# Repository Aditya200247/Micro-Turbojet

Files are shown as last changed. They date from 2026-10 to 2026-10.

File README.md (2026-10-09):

# Micro Turbojet: Parametric CAD + Cycle Physics

A parametric CAD model of a small **KJ66-class turbojet** (about 110 mm diameter, 234 mm long) built with [CadQuery](https://github.com/CadQuery/cadquery), plus a first-order thermodynamic estimate of how it would perform. Built as a college science/robotics project study, with the long-term goal of powering a small model fighter jet.

<table>
  <tr>
    <th align="center">Full-section view</th>
    <th align="center">Open-body (cutaway) view</th>
  </tr>
  <tr>
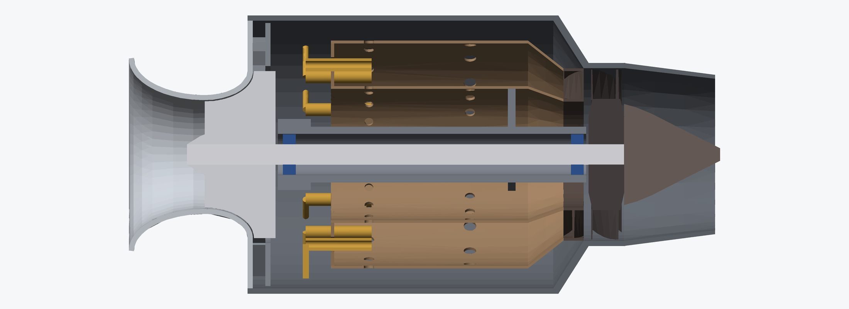
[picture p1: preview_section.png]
Full-section view of the turbojet
    <td align="center"></td>
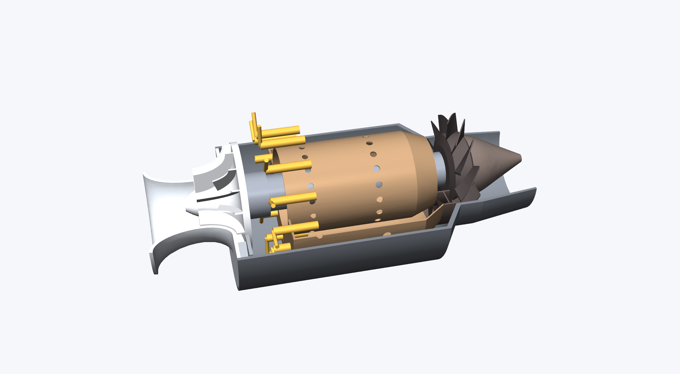
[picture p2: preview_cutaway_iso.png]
Open-body cutaway view of the turbojet
    <td align="center"></td>
  </tr>
  <tr>
    <th align="center" colspan="2">Open-body (cutaway) view, from above: compressor, combustor, turbine and nozzle</th>
  </tr>
  <tr>
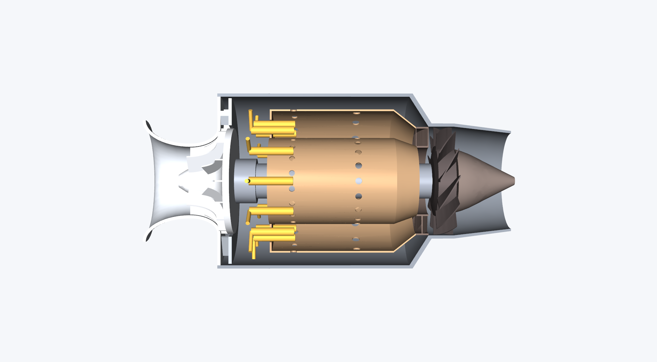
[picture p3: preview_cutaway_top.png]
Top-down cutaway of the turbojet
    <td align="center" colspan="2"></td>
  </tr>
</table>

> **Status: design study, not a validated engine.** The geometry is a believable first draft. It has not been CFD-checked, stress-checked, balanced, built or run. See [Known limitations](#known-limitations) before you machine anything.

---

## Contents

1. [Repository layout](#repository-layout)
2. [How a turbojet works](#how-a-turbojet-works)
3. [The physics, stage by stage](#the-physics-stage-by-stage)
4. [Results for this design](#results-for-this-design)
5. [CAD model description](#cad-model-description)
6. [Known limitations](#known-limitations)
7. [Rebuilding the model](#rebuilding-the-model)
8. [Scaling up to a 1–2 m fighter jet](#scaling-up-to-a-12-m-fighter-jet)
9. [Safety](#safety)
10. [References](#references)

---

## Repository layout

```
cad/        STEP (editable, named parts, colours) and STL (mesh) exports
            turbojet.step / .stl             complete engine
            turbojet_cutaway.step / .stl     top half of static shells removed
images/     preview renders
src/
  build_turbojet.py    parametric model, 16 named parts -> STEP/STL
  build_cutaway.py     open-body variant
  engine_calcs.py      mean-line cycle estimate used in this README
```

Units are **millimetres**. The engine axis is **+X**; the inlet lip is at x = 0 and the nozzle exit at x ≈ 234.

---

## How a turbojet works

A turbojet is a heat engine running the **Brayton cycle**, in four steps:

1. **Compress** the incoming air (compressor wheel and diffuser).
2. **Add heat** by burning fuel in it at roughly constant pressure (combustor).
3. **Expand** part of the hot gas through a turbine that extracts *just enough* work to drive the compressor.
4. **Expand the rest** through a nozzle into a fast jet. The leftover energy becomes thrust.

```mermaid
flowchart LR
    A["1 Inlet<br/>ambient air"] --> B["2 Compressor<br/>centrifugal, PR ≈ 3"]
    B --> C["3 Combustor<br/>annular, fuel added"]
    C --> D["4 Turbine<br/>axial, drives shaft"]
    D --> E["5 Nozzle<br/>jet = thrust"]
    D -. shaft work .-> B
```

Everything in the engine is one rotating assembly (compressor wheel, shaft, turbine wheel) spinning at **100,000+ RPM**, supported on two bearings.

---

## The physics, stage by stage

Notation: `T` temperature, `P` pressure, `U` blade speed, `c_p` specific heat, `γ` heat-capacity ratio, `η` efficiency, `ṁ` mass flow. Subscript `0` means total (stagnation) conditions.

### 1. Compressor: centrifugal wheel

Work input comes from **Euler's turbomachinery equation**. With no swirl at the inlet:

$$w_c = \sigma\,U_2^{2}$$

- `U₂ = πD₂N/60` is the blade tip speed (D₂ = 66 mm here).
- `σ` is the **slip factor**: the air leaves the wheel slightly "lagging" the blade. For radial blades the Wiesner correlation gives `σ = 1 − 1/Z^0.7`, where Z is the blade count (16 counting splitters, so σ ≈ 0.86).

The temperature rise and resulting **pressure ratio** follow from the isentropic relation with compressor efficiency η_c:

$$\Delta T_{0c}=\frac{w_c}{c_{p}},\qquad
PR_c=\left(1+\frac{\eta_c\,\Delta T_{0c}}{T_{01}}\right)^{\frac{\gamma}{\gamma-1}}$$

The pressure ratio rises as roughly **N²**, which is why these engines need such huge rotational speeds. The inducer's relative tip Mach number (`M = √(U₁ₜ² + Cₐ²)/a`) is kept below about 0.9 to avoid shock losses at the intake.

### 2. Diffuser

The air leaves the wheel at over 400 m/s, which is fast and kinetically "wasteful." The vaned diffuser slows it down, converting velocity into static pressure. A diffuser with too large an area change stalls (the flow separates), so vane angle and length matter.

### 3. Combustor: annular, vaporizer type

Fuel (kerosene or Jet-A) is injected into **vaporizer tubes** that sit in the hot flame zone, so the fuel boils before it mixes. Air enters the liner in stages:

- **Primary holes**: roughly stoichiometric burn at the front.
- **Dilution holes**: cool the gas from about 2000 K down to the turbine inlet temperature (TIT), around 1050 K here, which is the limit of what the turbine metal survives.

The fuel-to-air ratio comes from an energy balance:

$$f=\frac{c_{p,h}\,T_{03}-c_{p,c}\,T_{02}}{\eta_b\,H_{u}-c_{p,h}\,T_{03}}$$

with `H_u ≈ 43 MJ/kg` for kerosene. Real air is about 4× richer in oxygen than the primary zone needs, so overall the engine runs very lean (f ≈ 0.02). A pressure loss across the combustor of about 5% is assumed.

### 4. Turbine: axial, single stage

A ring of **nozzle guide vanes** (13) accelerates and turns the gas so it hits the **rotor blades** (12) at the right angle. The turbine must produce exactly the compressor's work, plus bearing and windage losses (mechanical efficiency η_m ≈ 0.98):

$$w_t=\frac{w_c}{\eta_m},\qquad
\Delta T_{0t}=\frac{w_t}{c_{p,h}},\qquad
PR_t=\left(1-\frac{\Delta T_{0t}}{\eta_t\,T_{03}}\right)^{-\frac{\gamma_h}{\gamma_h-1}}$$

The turbine is the most heat-stressed part of the engine: hot gas, high speed, high centrifugal load. Real hobby wheels are machined or cast from nickel superalloy (e.g. Inconel).

### 5. Nozzle and thrust

What pressure is left after the turbine is expanded through the nozzle. If `P₀₄/Pₐ` is above the critical ratio (about 1.85) the nozzle **chokes** (exit at Mach 1); otherwise the exit velocity is

$$V_e=\sqrt{2\,c_{p,h}\,T_{04}\,\eta_n\left[1-\left(\tfrac{P_a}{P_{04}}\right)^{\frac{\gamma_h-1}{\gamma_h}}\right]}$$

and for a static engine (no forward speed) **thrust** is

$$F=\dot m_{tot}\,V_e+(p_e-p_a)A_e$$

The second term is the pressure thrust, zero for a fully-expanded subsonic nozzle.

The nozzle exit *area* is not a free choice. By continuity, `ṁ = ρₑ Vₑ Aₑ`, so the exit area must match the flow. Too large and the turbine back-pressure drops; too small and the compressor surges.

---

## Results for this design

Produced by [`src/engine_calcs.py`](src/engine_calcs.py). Inputs read from the CAD model; efficiencies, speed and TIT are **assumptions** typical of hobby turbines.

**Assumptions:** 120,000 RPM, η_c = 0.75, η_t = 0.80, η_n = 0.95, η_m = 0.98, combustor ΔP = 5%, TIT = 1050 K, inducer axial velocity 110 m/s, ISA sea level.

| Quantity | Result |
|---|---|
| Compressor tip speed U₂ | 415 m/s |
| Slip factor | 0.86 |
| Specific compressor work | 147 kJ/kg (ΔT ≈ 147 K) |
| **Pressure ratio** | **3.1** |
| Inducer relative tip Mach | 0.86 |
| Air mass flow | 0.157 kg/s |
| Fuel-air ratio / fuel flow | 0.019 / ~11 kg/h |
| Turbine pressure ratio | 1.94 (ΔT ≈ 128 K) |
| Exhaust total temperature | ~920 K |
| Nozzle exit velocity | ~445 m/s (subsonic) |
| **Static thrust** | **~70 N** |

These are sensible numbers. Commercial KJ66-class engines quote around 80–110 N at 100–120k RPM with higher mass flow, so this model sits slightly under that range. The estimate is first-order (mean-line, constant specific heats, no tip-clearance, windage, or off-design effects) and should be trusted to roughly ±30%.

---

## CAD model description

16 named parts, all valid solids with **zero part-to-part interference** (checked pairwise with OpenCascade boolean intersection).

| Part | Notes |
|---|---|
| `intake_shell` | Elliptical bellmouth to compressor shroud |
| `compressor_wheel` | Ø66 mm, 8 main + 8 splitter blades, radial exit |
| `diffuser` | 15 straight vanes at 22° |
| `casing` | Ø110 mm outer, converges to the nozzle |
| `combustor_outer / _inner / _dome` | Annular liners with primary + dilution holes |
| `fuel_system` | Fuel ring, 12 feed stems, 12 vaporizer tubes |
| `ngv` | 13 twisted nozzle guide vanes in two end rings |
| `turbine_wheel` | Ø67 mm, 12 twisted blades |
| `shaft` | Ø8 mm |
| `bearing_tunnel`, `bearing_front`, `bearing_rear` | Shaft housing and two bearing seats |
| `support_spider` | Three struts holding the bearing tunnel |
| `exhaust_cone` | Tail cone |

---

## Known limitations

Please read these before using the model for anything real.

1. **Nozzle exit area is too large.** The cycle calculation needs roughly **850 mm²** of exit area at design flow; the CAD has about **2,780 mm²** (3.3× too big). Built as drawn, the turbine would see low back-pressure and the engine would not hold its design point. The nozzle needs to be necked down (exit diameter of about 45–50 mm is the usual KJ66 range).
2. **Blades are placeholder shapes.** Compressor and diffuser blades are flat plates; turbine and guide-vane blades are simple twisted rectangles, not designed aerofoils. Real performance depends on velocity triangles, blade angles and tip clearance, which need CFD or turbomachinery design tools.
3. **No structural, thermal or rotor-dynamic analysis.** Disc stress at 120k RPM, blade resonance, critical speeds and thermal growth were not checked.
4. **Missing systems:** no starter, fuel pump/valve, ignition, oil system, ECU, mounting, or instrumentation. The shaft has no lock-nut or balancing features.
5. **Bearing housing is simplified.** The rotor is held by three thin struts and plain bearing seats; there is no preload spring or cooling-air path.
6. Efficiencies, TIT and mass flow in the physics are assumed, not measured.

---

## Rebuilding the model

Requires Python 3.9+ and CadQuery (`pip install cadquery`).

```bash
pip install -r requirements.txt
python src/build_turbojet.py cad      # full engine  -> cad/turbojet.step / .stl
python src/build_cutaway.py cad       # open body    -> cad/turbojet_cutaway.step / .stl
python src/engine_calcs.py            # cycle estimate
```

Run the scripts from the repo root; `build_cutaway.py` imports `build_turbojet.py` from `src/`. Dimensions are plain numbers inside each part function. Blade counts are constants at the top of `build_turbojet.py`.

**Opening in CAD:** use the `.step` files. They preserve solids, part names and colours. Fusion 360 (Data Panel → Upload), SolidWorks (File → Open, tick "Import as assembly"), Onshape (Import), and FreeCAD (File → Open) all read them. Check that units are set to mm. The `.stl` files are meshes for 3D printing or Blender only.

---

## Scaling up to a 1–2 m fighter jet

- A hobby jet of **1–1.5 m** typically uses one **80–150 N** turbine. A 2 m airframe usually needs more thrust, or twin engines.
- Rule of thumb for model jets: **thrust ≥ ½ of take-off weight** for comfortable flight, ideally closer to 1:1 for aerobatics.
- **Inlet and exhaust ducting** dominate the airframe design: smooth, short inlet ducts (low pressure loss) and a heat-shielded tailpipe matter as much as the engine.
- The engine's thrust *changes* with forward speed and altitude; static thrust is only the starting point.
- For a college project, **buying a certified commercial micro-turbine** and designing the airframe around it is far safer than building one. This repo can supply an accurate dummy engine for fit-checking.

---

## Safety

Real turbojets are dangerous: rotors turn at 100,000+ RPM and a failure releases fragments at high energy; exhaust is over 600 °C; the fuel is flammable. **Do not run any engine built from this design** without proper engineering review, containment, balancing, test-cell safety, and supervision from your institution. Parts of this model are not validated.

---

## References

- H.I.H. Saravanamuttoo et al., *Gas Turbine Theory*, Pearson. Cycle analysis, compressors, turbines.
- S.L. Dixon & C. Hall, *Fluid Mechanics and Thermodynamics of Turbomachinery*, Butterworth-Heinemann. Euler work, slip, velocity triangles.
- J.S. Wiesner, "A Review of Slip Factors for Centrifugal Impellers", *J. Eng. Power*, 1967. Slip factor correlation.
- T. Kamps, *Model Jet Engines*, Traplet. Hobby-scale turbojet construction.
- [CadQuery documentation](https://cadquery.readthedocs.io/)

---

**By Aditya Kumar Thakur**

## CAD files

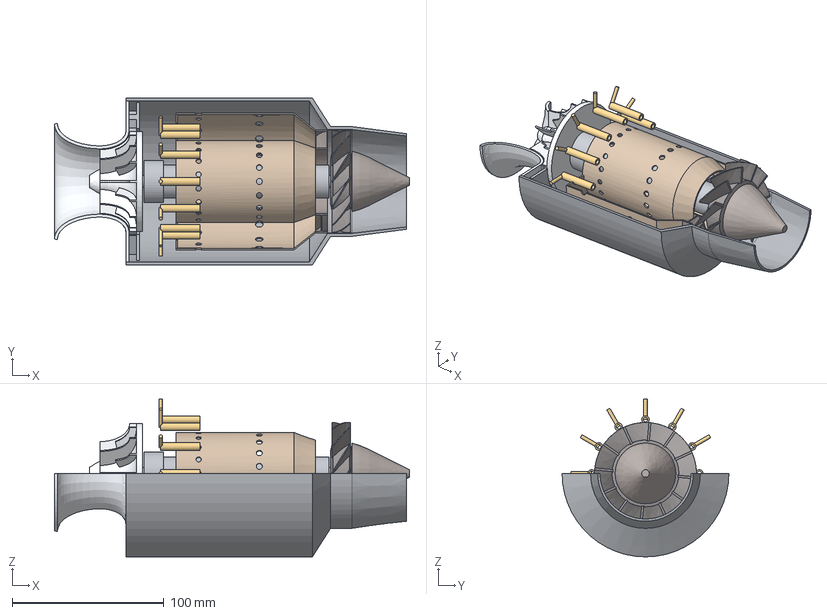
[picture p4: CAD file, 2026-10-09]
turbojet_cutaway.step
234.0 x 110.0 x 104.0 mm
intake_shell
compressor_wheel
diffuser
casing
combustor_outer
combustor_inner
combustor_dome
fuel_system
ngv
turbine_wheel
shaft
bearing_tunnel
bearing_front
bearing_rear
support_spider
exhaust_cone

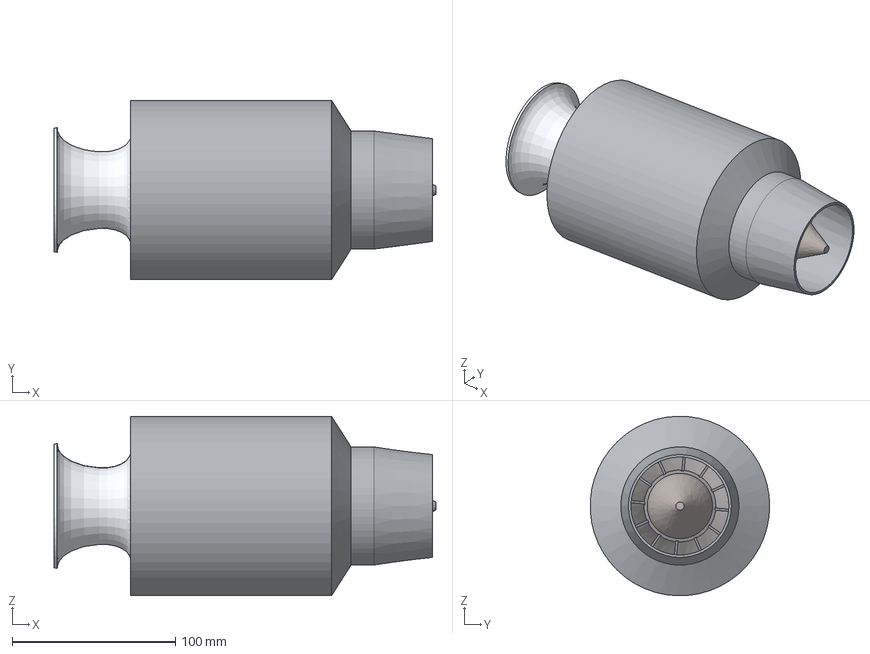
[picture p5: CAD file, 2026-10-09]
turbojet.step
234.0 x 109.9 x 109.9 mm
intake_shell
compressor_wheel
diffuser
casing
combustor_outer
combustor_inner
combustor_dome
fuel_system
ngv
turbine_wheel
shaft
bearing_tunnel
bearing_front
bearing_rear
support_spider
exhaust_cone

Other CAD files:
turbojet.stl
turbojet_cutaway.stl
